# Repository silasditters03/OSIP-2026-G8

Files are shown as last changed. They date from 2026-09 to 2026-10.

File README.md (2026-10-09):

# Open Hardware Documentation Challenge

## TLDR
Read the [detailed instructions](/Hardware/detailed_instructions.md) for guidance on printing, assembling and testing the gearbox.

## Description
This repository presents a small hardware project for the course Open Science for Physicists (NS-PH500M) at Utrecht University. The goal of this repository is to be a starting place for all students to find the basic documentation which they can then use the template to build up. Update it regularly and as you make choices to make it useful for the next set of students who will have to recreate your project (hopefully with better documentation). 

[How to use Markdown, GitHubs formatting language](https://docs.github.com/en/get-started/writing-on-github/getting-started-with-writing-and-formatting-on-github/quickstart-for-writing-on-github)

## Main features
_The original project is based on work from Zach Meredith who used a gear box to convert a quickly spinning motor into a more slowly spinning display plate in our Leapfrog Bolt 3D printer_ 

Each subfolder contains a `_readme.md` file that explains the conventions and purpose of that folder for the (future) collaborators to keep it tidy.

In the results section you can see the end product of his gearing system using an open box version of the gear box. This allows the different components to be viewed. 

In hardware you can find the STL files to be printed as well as the fusion files which would allow you to tinker with the gear ratios. You can also can find an overview of the necessary steps to produce the parts and assemble the gearbox. 

This template is adjusted to the typical needs of a hardware project made for research or education. 

## Build instructions
_The best way to start this is by looking at the results and seeing how the gear box drives the platform. Then consider what the needs for your gear box are. What frequency should it spin at and what should it be made of. If you feel confident with 3D modelling you could then edit the gears or choose among the selection of gears present to allow a sufficient step down. Then 3D print the gears in LPL and assemble the box. Play with power, distribution of force and gearing to allow the LPL scanner platform to spin as close to 50 RPM and as close to 8 RPM for 2 minutes at a (relatively) constant speed. 

## Team
_Even though platforms such as github show a list of user accounts for contributors for a project or repository, the past contributors or external collaborators also deserve a place here_

+ Project initiators: Edward Paddon and Alexis Gilbert
+ Contributors: 
	Zach Meredith,
	Pieter Kooijman,
	Daan van der Putten

## License

This project is released under CC0 1.0 Universal. 
You can modify an reuse as you like.

### (How to cite:)
LPL and open physics colab, Utrecht University, 2026

## (Funding)
No direct funding

This template can be copied free of charge. 

<div style="display: flex; justify-content: space-between;">
  lpl sharing
  <figcaption>Figure: LPL shop front with current and future letters<figcaption>
</div>

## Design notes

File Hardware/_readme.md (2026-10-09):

# Hardware description
_In this subfolder you can describe the hardware involved in this prototype. Include a parts list below, fabrication methods and build instructions. Complex build instructions can be split into in separate documents in this folder._

## Parts List

|Description| Amount | Where |
|---|---|---|
|3D printed parts | 8 / 9 | Github / LPL | 
|Nuts  | 4 | jobshop | 
|bolts | 6 | jobshop | 
|washers/spacers  | 5-7 | jobshop | 
|Bearing  | 1 | jobshop | 
|axle / shaft  | 1 | jobshop | 
|Motor  | 1 | lpl | 
|Powersupply  | 1 | lpl | 
|Shaft friction distributor  | 1 | n/a | 

## Fabrication methods and tools
- 3D printer
- Metal Saw
- Power supply
- Spinning plate for test

## Build instructions
_for complex instructions, cut it down into overarching build steps here and [link](detailed_instructions.md) to the detailed documents_

3D print the gears using a suitable filament that can withstand friction and temperature. Mount the gears on shafts and interlock them with each other. Assemble the gear box. Power the motor using a power supply. A breadboard can help control power using resistors. The motor output slips which you can reduce with a 3D printed cover. This allows it to apply force to different materials or objects.

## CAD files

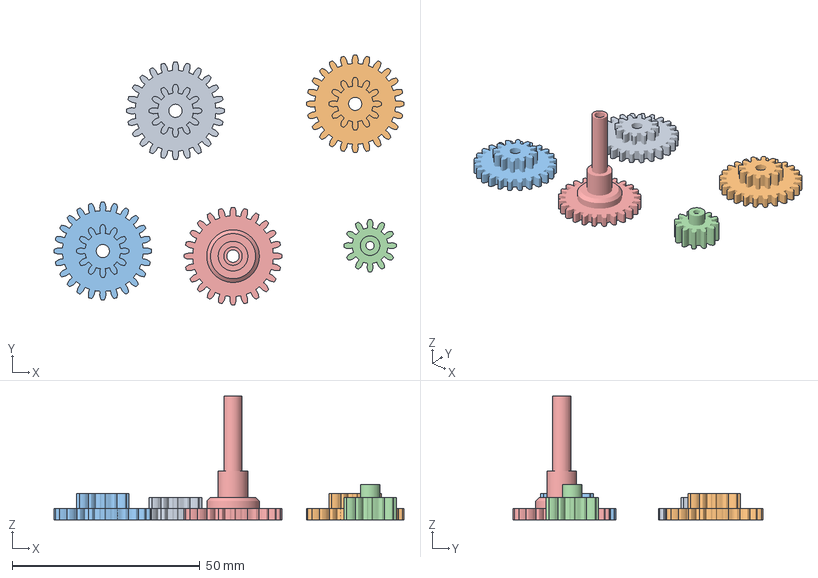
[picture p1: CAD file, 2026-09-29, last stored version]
Hardware/JakeGear.3mf
93.2 x 66.6 x 33.0 mm
Gearbox_24tooth_v2
Gearbox_24tooth2_v2
Gearbox_24tooth3_v2
Gearbox_drivegear_v2
Gearbox_engaginggear_v2

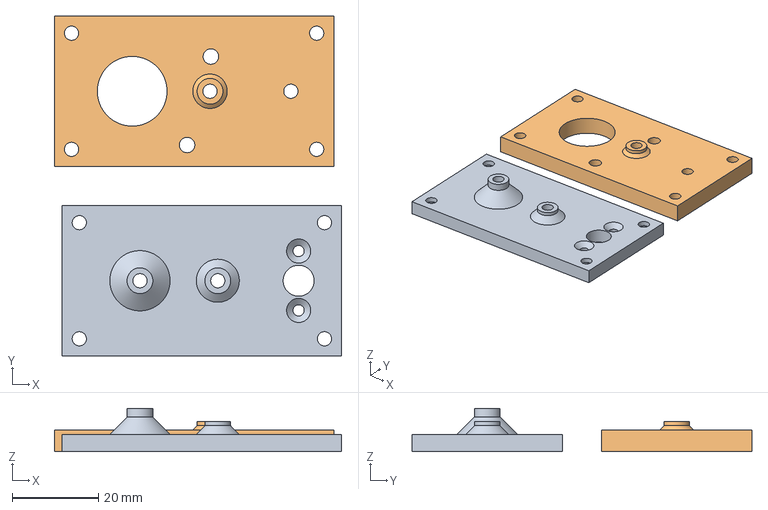
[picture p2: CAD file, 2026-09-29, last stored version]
Hardware/JakeBase.3mf
66.8 x 79.1 x 10.0 mm
Gearbox_housing_baseplate_v2
Gearbox_housing_topplate_v2

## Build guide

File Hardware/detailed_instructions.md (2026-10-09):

# Detailed instructions

This document shows the detailed step-by-step instruction for building and testing the gearbox. 
It is split up into three segments. Segment 1: 3D-Printing, Segment 2: Assembly and Segment 3: Testing

## Segment 1: 3D-Printing
1. Load the correct fillament in the printer. For this project we recommend PLA as a fillament.
2. When the printer is ready to print, head over the the PC in LPL and open PrusaSlicer.
3. The .step files that need to be sliced can be found in the Hardware folder
4. When opening .step files in Prusaslicer, you can drag in multiple files at once. This is recommended to save time.
    We put all the gears in one slice and the box components in a seperate one.
5. When placing the objects in PrusaSlicer make sure they are oriented with the most surface area down. (driver_gear.step and top_plate_v2 must be flipped in z-axis to accomplish this, others are already fine_=)
6. Once the desired objects are placed, we can assign printing settings. First, on the right hand side, select the correct printer
7. Select the correct print settings. You want to select the distance that is about 1/2 the nozzle diameter of the printer you will use.
    Select STRUCTURAL for sturdier builds that take longer and SPEED for faster prints that are less sturdy.
8. Select the correct fillament (this can be found on the fillament role on hanging on the printer)
9. If needed, select the correct support and brim. A brim is recommended for prints with less surface area touching the bed, or prints that are taller than they are wide.
10. If all previous steps were successful, you can now slice (bottom right)
11. Transfer sliced .gcode to printer. The PCs in LPL are connected with the 3D-printers. You can transfer a sliced build to the printer with the button in the bottom right (next to the large "Export g-code" button)
12. Once its sent to the printer, head over to it. On the screen you will be prompted to start the print.
NOTE: If you are printing at temperatures above 170 °C, the nozzle will first calibrate and go to a temperature below your printing temperature. This will take a bit, but when done it will automatically go to the higher
        printing temperature, so do not panic!

## Segment 2: Assembly
1. Collect all printed parts, you should have: A housing top plate, housing bottom plate, 4 housing pillars, 1 driving gear, 1 enganging hear, 3 24-tooth gears of different heights.
2. Get a motor from the storage in the workshop. Open the drawer which says Electronic components 4 and actuators and grab a 6 Volt motor (to the left). 
3. Leave the protolab and go the storage unit in the middle of the workplace and open the 'ball bearings' drawer and grab 1 bearing which is in a plastic casing called 'IBB  688-2RS NI25J'. This should fit perfectly in the topplate you printed. 
4. From the drawers at LPL (by the tables) collect the following: 4 bolts, 4 bolt screws (thin enough to pass through the pillars), 3 screws/pins (from 'Allen bolts, keys and pins' that fit through the gears and are long enough to go all the way through
5. In the map Documents -> Images you can find 5 images that'll help you. Open the drawer you see in the picture below titled 'M1 tot en met M2,4'.
<figure style="display: flex; justify-content: space-between;">
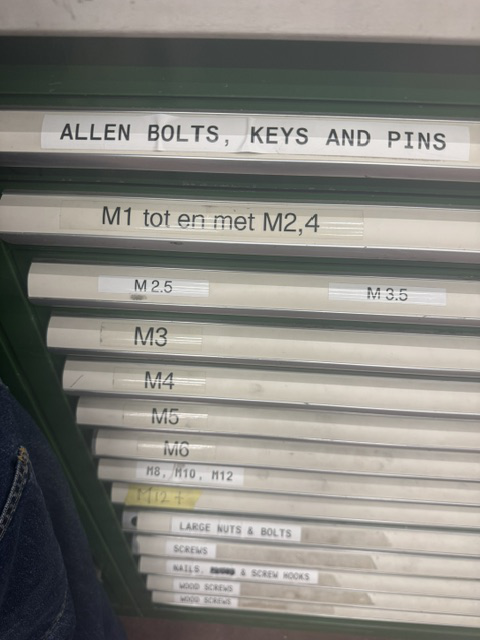
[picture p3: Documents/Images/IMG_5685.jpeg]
  
  <figcaption>Open the drawer titled 'M1 tot en met M2,4'. <figcaption>
</figure> 
      
Now pick 2 screws out of the pink box you see in the second image. These 2 screws let you attach the motor to your baseplate. 
   
<figure style="display: flex; justify-content: space-between;">
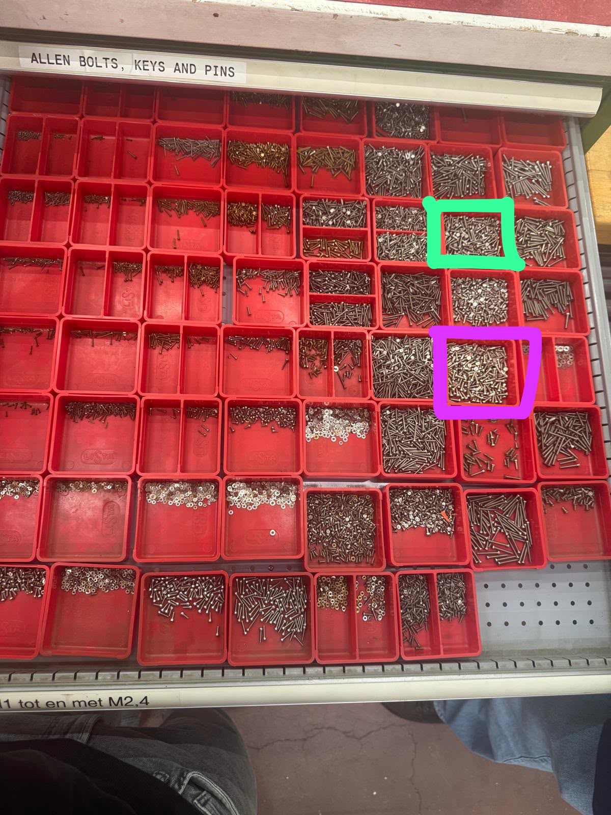
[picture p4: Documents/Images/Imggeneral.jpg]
  
  <figcaption>Pick 2 screws from the pink box.<figcaption>
</figure>  

6. Next, open the 'M4' drawer and grab 5 spacers you see in the image surrounded by blue.  You will need them to space out the cogs. 
</figure> 
   
<figure style="display: flex; justify-content: space-between;">
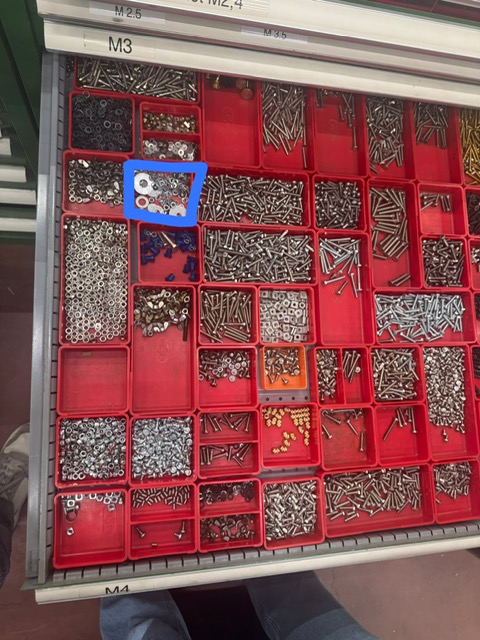
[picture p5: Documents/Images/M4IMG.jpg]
  
  <figcaption>Grab 5 small spacers from the box that is surrounded in blue.<figcaption>
</figure>

7. Now use all the materials to build the gearbox. In the photos you can see how we built the gearbox. The most important thing to see in the images is the order you place the gears in. The height of the small part of the 3 similar cogs should be the smallest for the fourth gear (seen from the motor).   There is 1 spacer between the base plate (motor side) and the 2nd gear (2nd from the motor side), 2 spacers between the base plat and the 3rd cog. 1 between the 2nd and 4th cog and 1 between the 3rd and 5th cog. We use the bolts to attach the pillars to both plates. We also used some tape to make sure the gears wouldnt get loose. 
  
<figure style="display: flex; justify-content: space-between;">
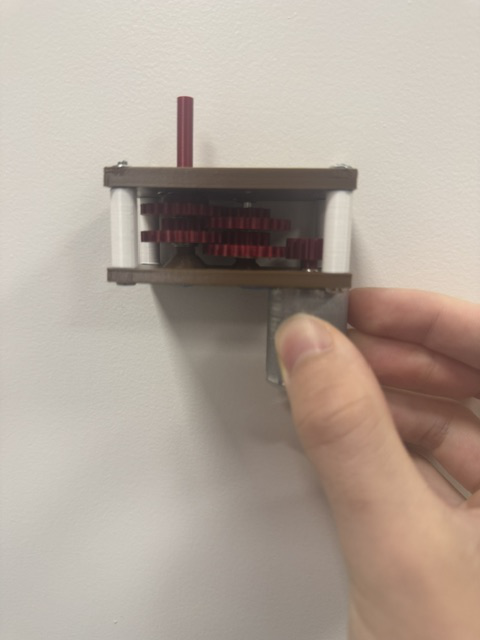
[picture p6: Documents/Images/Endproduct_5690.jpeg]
  
  <figcaption><figcaption>
</figure> 
<figure style="display: flex; justify-content: space-between;">
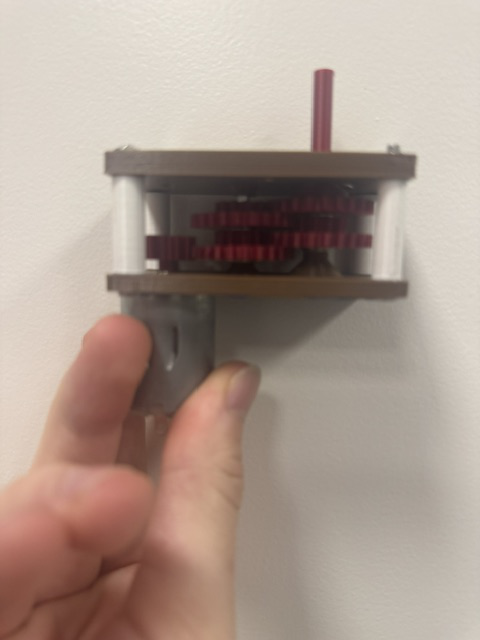
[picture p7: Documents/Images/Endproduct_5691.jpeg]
  
  <figcaption><figcaption>
</figure> 

## Segment 3: Testing

1. To measure the rotational output of the now motorized gearbox, we need to transfer its torque to the rotating platform. To do so follow these steps:
2. Attach a rubber wheel to the output. Insert a plastic tube (we don't know what it is, maybe a section of cable covering) inside the wheel to make the output fit tightly. This was not enough for our model so covering the output shaft with tape is encouraged to increase its thickness.

<figure style="display: flex; justify-content: space-between;">
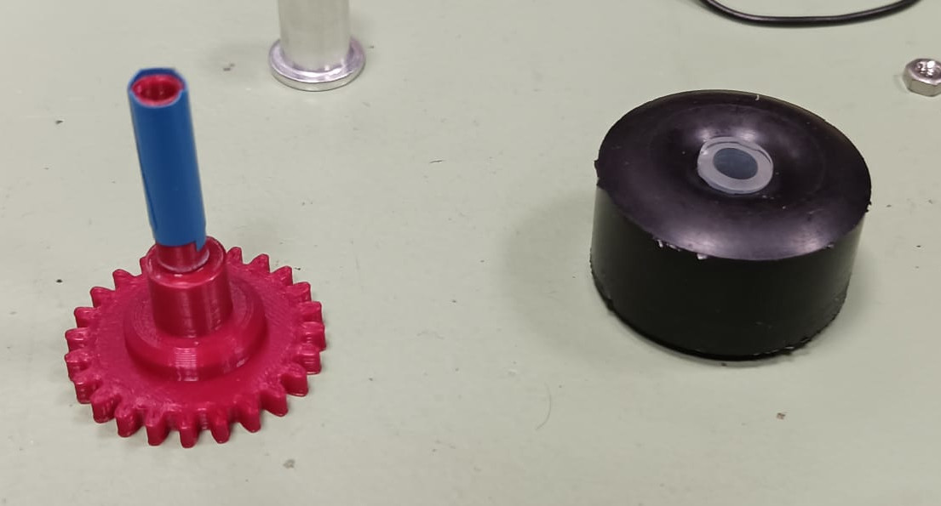
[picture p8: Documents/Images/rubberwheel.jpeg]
  
  <figcaption><figcaption>
</figure>

3. Then, use a clamp and one of the casings (some are broken, some are too loose and other too tight) in the protolab to fix the motor to the table. We chose a somewhat loose casing and added padding with a folded sheet of paper. Put the rotating platform in contact with the rubber wheel. In the image the system is in motion already but you get the idea of the placements.

<figure style="display: flex; justify-content: space-between;">
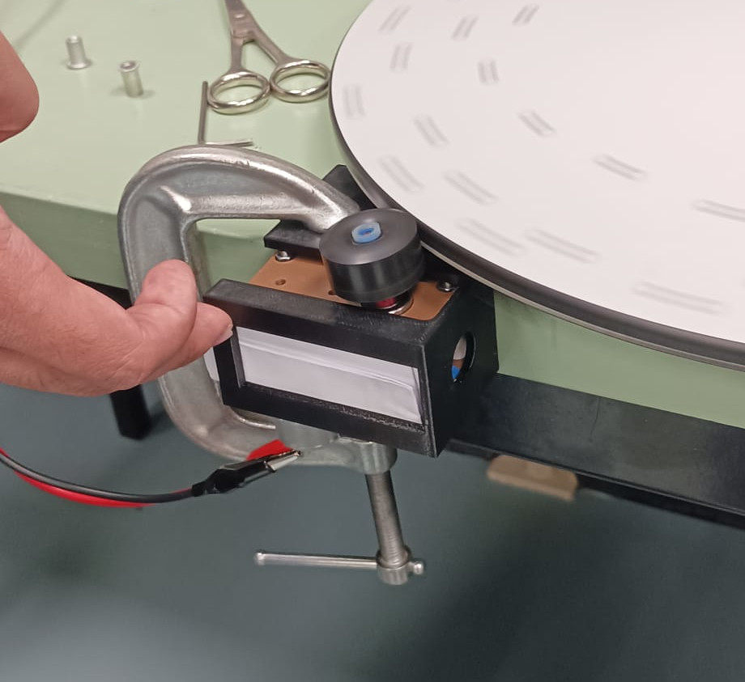
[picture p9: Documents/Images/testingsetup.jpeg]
  
  <figcaption><figcaption>
</figure>

4. There should be an already assembled Arduino mounted on a protoboard. Coming out of the board there is a magnet sensor, tape it to the table, underneath the rotating platform. Use the Arduino IDE on a computer to upload the [code](../Software/tachometer.ino), don't forget to select the Arduino NANO model on the IDE. There are magnets every 1/4th of circumference on the rotating platform, which the sensor detects and the code translates into rpms.

<figure style="display: flex; justify-content: space-between;">
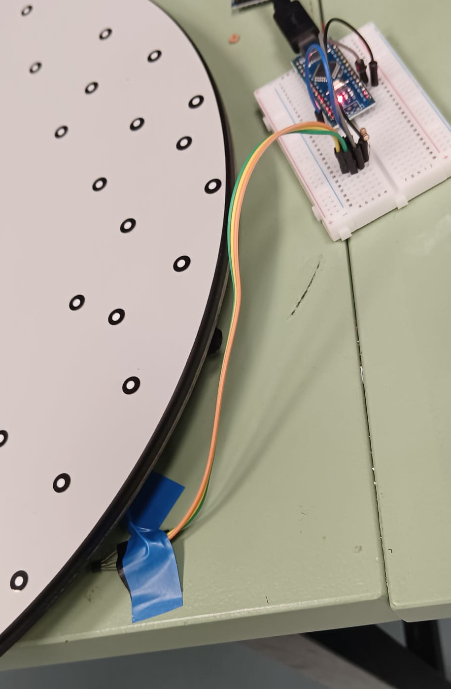
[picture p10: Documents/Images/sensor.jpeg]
  
  <figcaption><figcaption>
</figure>

5. Lastly, plug the motor into a DC power supply. Our results for different volts and amperages can be found in [Results](../Results/sensor_readings.txt). Don't fry the motor or break the shaft! (Last one happened to us, luckily is just a 13min print).

Good luck!

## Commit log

2026-09-29 Upload PrusaSlicer files
    [JakeBase.3mf, JakeGear.3mf]
2026-10-06 Update detailed instructions for gearbox assembly
2026-10-06 Enhance gearbox build instructions
    Added detailed step-by-step instructions for building the gearbox, including 3D printing and assembly segments.
2026-10-06 Revise gearbox building instructions and correct errors
    Updated detailed instructions for building the gearbox, including 3D-printing and assembly steps. Corrected filament spelling and clarified assembly materials.
2026-10-06 Revise gearbox building instructions
    Updated detailed instructions for building the gearbox, including 3D-printing and assembly steps.
2026-10-06 Revise gearbox building instructions
    Updated detailed step-by-step instructions for building the gearbox, including 3D-printing and assembly segments.
2026-10-06 Revise gearbox construction instructions
    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
2026-10-09 Revise gearbox instructions to include testing segment
    Updated detailed instructions for building and testing the gearbox, adding a new segment for testing and improving clarity in the assembly process.
2026-10-09 Add sensor rpm readings and V/A values
    Raw data output from the Arduino while testing for different rps alongside with the voltage and amperage provided to the motor
2026-10-09 Revise detailed instructions for gearbox assembly
    Mention Arduino NANO model and fix clariy
